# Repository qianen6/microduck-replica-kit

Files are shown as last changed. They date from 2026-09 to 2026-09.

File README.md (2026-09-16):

<!-- changed_branch: main -->
<!-- changed_field: release_snapshot,publication_metadata,readme.community -->
<!-- repository_state: public_ready -->
<!-- release_snapshot: r9_2026_09_16 -->

# Microduck Replica Kit 🦆

**Microduck 社区复刻工程资料 · R9 工程试装版**

整理机械模型、打印文件、硬件路线和数字检查证据，便于复现与交流。当前路线为 **Pi Zero 2 W + OpenRB-150 + 15 个 HD-1910 + OV5647**；最新机械修订来自 2026-09-13，11 件试装打印工程来自 2026-09-14。

> 独立社区项目，与 Pollen Robotics / Hugging Face 无隶属或背书关系。数字检查通过不等于实物、电气或整机制造验证通过；当前仍为工程试装版。

## 从这里开始

| 你想做什么 | 入口 |
|---|---|
| 查看 / 编辑最新整机 | [R9 Blender 模型](models/r9/Microduck_R9_trial.blend) |
| 获取当前 39 件打印几何 | [STL 文件夹](models/r9/stl) · [逐件清单和 SHA-256](models/r9/parts-manifest.json) |
| 在 Bambu Studio 打开试装排版 | [11 件、两盘、已启用支撑的 3MF](printing/r9/R9_11_parts_support.3mf) |
| 理解文件区别、打印单位与使用顺序 | [打印说明](printing/r9/README.md) |
| 查看 R9 修改及未闭合问题 | [工程评估](docs/current/engineering-review.md) · [原始数字检查摘要](models/r9/evidence) |
| 查看当前硬件路线 | [硬件状态表](hardware/CURRENT_HARDWARE.md) |
| 查阅旧版螺丝、材料、接线与选型 | [历史资料索引](docs/history/README.md) |
| 检查本次发布内容与脱敏策略 | [发布说明](docs/PUBLISHING.md) · [验证记录](VERIFICATION.txt) |

## 当前状态

| 项目 | 状态 |
|---|---|
| 当前整机场景 | 113 个对象；39 件打印对象，15 个舵机参考 |
| R9 几何修订 | 11 个原有网格 + 2 个新增打印件；13 个修订网格历史检查闭合、单连通 |
| 相机与电池 | OV5647 孔位/镜头偏置修订、相机承架、可拆电池后盖 |
| 发布文件复核 | 脱敏前后网格、变换、父子层级与材质分配一致；3MF 的 3D 成员一致 |
| 打印工程 | 11 件试装子集，**不是 39 件全机打印包**；保留支撑设置，不发布机器 G-code |
| 实物配合、电气、动力学与行走 | 尚未完成；不得把静态几何检查当作整机验证 |

历史运动抽样覆盖 235 个姿态，仍记录 82 条新增材料相交；其中包含旧模型已存在的阻挡和名义配合。完整运动范围、轴向叠层和负载试验仍待闭合，详见工程评估。

## 快速使用

```bash
git clone https://github.com/qianen6/microduck-replica-kit.git
cd microduck-replica-kit
python tools/verify_publication.py modified
```

Blender 文件可用 Blender 5.2.1 打开；STL 以毫米为单位，采用零件局部坐标，切片前需确认朝向和尺寸。3MF 面向 Bambu P1S / 0.4 mm 喷嘴与纹理 PEI 板，材料与支撑需按自己的机器重新确认、重新切片。

先试装相机承架、电池盖及单关节，再扩展整机。电池标称输出范围、板卡端口额定值不构成 15 舵机动态供电余量证明。

### 重建上游参考装配（历史参考）

```powershell
powershell -ExecutionPolicy Bypass -File scripts/fetch_upstream.ps1
python -m venv .venv
.\.venv\Scripts\python.exe -m pip install -r requirements-geometry.txt
.\.venv\Scripts\python.exe scripts/export_reference_assembly.py upstream/microduck_rl generated/reference-assembly
```

该脚本重建锁定的上游仿真参考，不生成本仓 R9 改件。旧 Rev A 的 XL330 BOM 也不是当前 HD-1910 采购清单。

## 目录

```text
models/r9/          当前 Blender、39 件 STL、逐件清单及历史数字检查
printing/r9/        11 件试装 3MF 与打印说明
hardware/           当前路线说明及旧 Rev A BOM
docs/current/       R9 工程评估
docs/history/       R3–R8 选型、接线、紧固件与材料参考
firmware/reference/ 原厂 OpenRB 桥接参考（非已验证 HD-1910 驱动）
scripts/            上游参考获取和装配导出
tools/              可重复运行的发布检查
proof/              发布差异、哈希及脱敏复核摘要
```

## 交流群：鸭子复现

欢迎交流复刻、打印试装和问题复现。下图由项目维护者提供并指定公开用于入群。

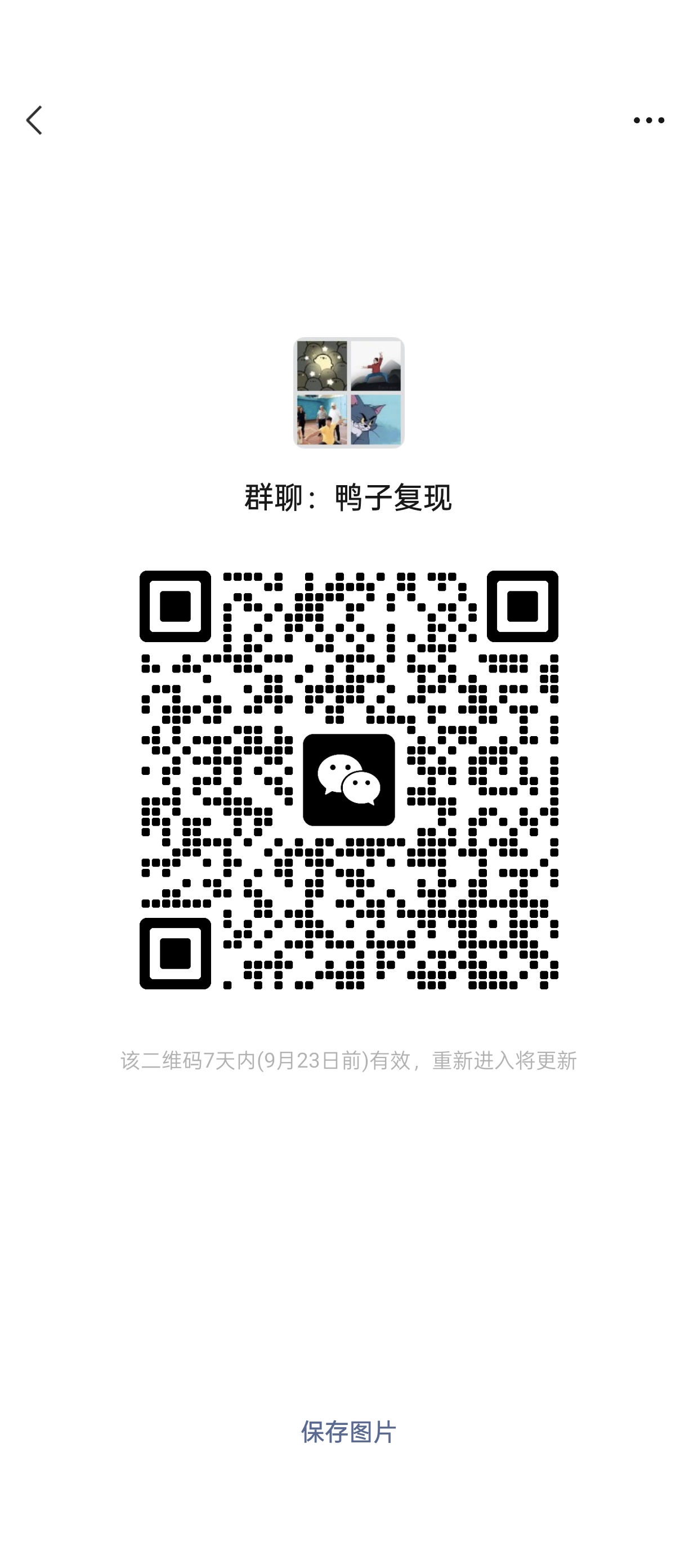
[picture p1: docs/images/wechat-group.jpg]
微信群：鸭子复现


**有效期：图片注明 7 天内、9 月 23 日前有效（本次发布于 2026-09-16）。** 到期后请通过仓库 Issue 请求更新二维码。二维码是本次明确保留的公开联系入口，其余个人/设备信息不随工作区上传。

## 来源与许可证

- [pollen-robotics/microduck](https://github.com/pollen-robotics/microduck)：运行时与控制栈。
- [pollen-robotics/microduck_rl](https://github.com/pollen-robotics/microduck_rl)：仿真几何与训练栈，锁定版本见 [source-lock.json](source-lock.json)。
- [fanhao375/microduck-replica](https://github.com/fanhao375/microduck-replica) 与 [飞特 v2.0 CAD 参考](https://github.com/fanhao375/microduck-replica-cad/releases/tag/v2.0)：复刻研究及 R9 局部接口参考。
- [ROBOTIS OpenRB-150](https://github.com/ROBOTIS-GIT/OpenRB-150)：原厂串口桥接示例。

本仓原创代码和文字使用 Apache-2.0；上游 Microduck 模型衍生的 Blender、STL、3MF 几何按 CC BY-NC-SA 4.0 保留署名与相同方式共享要求。第三方器件外观仅为装配参考，不冒充原厂开放硬件。群二维码仅用于本项目入群，不作模型或代码许可证授权。详见 [NOTICE.md](NOTICE.md)。

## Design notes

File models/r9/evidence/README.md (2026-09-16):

# R9 历史数字检查

本目录保存 2026-09-13 的检查结果及修订计划，经过路径脱敏。不是本次重新运行的动态/电气认证。本次发布仅验证模型几何保持、39 件 STL 导出、3MF 几何与设置保持及隐私检查。

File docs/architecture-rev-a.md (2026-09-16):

# Functional-compatible Rev A

## Target

`functional_compatible_rev_a` preserves the public kinematic layout and the upstream 61-observation / 14-policy-action contract while replacing unavailable manufacturing data with staged measurement and self-designed electronics.

## Architecture

| Subsystem | Rev A target | Evidence state |
|---|---|---|
| Compute | Radxa Zero 3W, RK3566 | high confidence from runtime/device-tree evidence |
| Actuation | 15 compact smart servos; XL330-compatible baseline | high confidence for count and bus layout |
| Policy joints | 14; mouth excluded from policy action | verified in runtime/model |
| Servo bus | UART2, 1 Mbps, 3.3 V TTL half duplex | verified in runtime |
| IMU | LSM6DSV16X, Dynamixel-like ID 200 prototype | data contract verified; PCB absent |
| Depth | VL53L8CX-class 8×8 ToF | optional until locomotion bring-up |
| Camera | IMX219-class CSI camera | optional until locomotion bring-up |
| Battery | removable pack; final rail frozen after bench test | hardware implementation unresolved |
| Audio/NFC | deferred from locomotion Rev A | not required by 50 Hz control loop |

## Stage gates

| Gate | Build | Pass condition |
|---|---|---|
| G0 | source-only | locked commits and deterministic reference export |
| G1 | one actuator | 50 Hz for 30 min; current, voltage, temperature and packet-loss log |
| G2 | print coupon | repeatable M2 insert and bearing fits |
| G3 | one leg | full travel, no harness pinch, 10 min static support |
| G4 | full bus | 15 actuators + IMU; complete read/write within 20 ms |
| G5 | suspended robot | home, sit/stand and fall-to-limp before gait execution |

## Key design rule

Do not bulk-purchase the remaining actuators or freeze battery/PCB design before G1 and G2. The first prototype is a measurement instrument, not a production unit.

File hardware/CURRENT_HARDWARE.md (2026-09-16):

# 当前硬件路线：R9 工程试装

| 模块 | 当前模型对应 | 验证边界 |
|---|---|---|
| 主控 | Raspberry Pi Zero 2 W | 安装参考；系统与真实线束另验 |
| 总线候选 | OpenRB-150（头内） | 原厂桥接为协议参考；HD-1910 主机协议、接插件、电气尚待验证 |
| 舵机 | 15 × HD-1910-C001 | 舵盘配合、轴向叠层、总线及峰值电流待台架 |
| 相机 | OV5647，25 × 24 mm PCB | 孔距 21 × 12.5 mm；板厚 1.2 mm 为模型假设 |
| IMU | BNO08x 板参考 | 实际板型/驱动/时序待确认 |
| 电池 | 6.4 V 磷酸铁锂，19 × 37 × 66 mm 包络 | 商品标示输出 0–3 A；不是已实测连续输出能力 |
| 降压 | MP1584 5 V 模块候选 | 热、压降和带载余量待实测 |
| 开关/声音 | 小拨动开关与 20 mm 扬声器参考 | 电流承载与驱动匹配另验 |

这是硬件路线表，不是完整可下单 BOM。`BOM_REV_A.csv` 是旧 XL330 路线；历史 R6 HAT 接线和 R8 螺丝资料保留版本标签，不能直接用于 R9 全机采购/通电。不得把 3 A 端口或电池广告范围当作 15 舵机电源设计验证。

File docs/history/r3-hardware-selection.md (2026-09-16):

> 历史参考：对应旧版硬件/几何；不得视为 R9 当前 BOM、接线或打印放行。

# Microduck硬件定选与实施方案

> 一套明确的样机硬件主选方案，含采购、接线、改模和验证顺序。

**生成日期:** 2026-09-05

**预计总投入:** 首轮工程时间盒40小时；非交货承诺，物流、返工和完整步态训练另计

---

## 1. 已确认的用户需求简报

- **目标:** 确定一台Microduck复刻样机采用的部件和制作路线，减少反复购买和凭占位图打印。
- **当前起点:** 已有RA2静态模型和采购表；用户指定HD-1910-C001资料包。附件SHA-256：252dad0edfd1560d9bfe5561e065ce00294942c0ce94806dbf183d2f08c6c105，与项目留档相同；图纸页1与照片是舵机参数来源。
- **可用时间:** 按首轮40小时工程时间盒拆解；并非用户已承诺可用工时。
- **语言:** 中文
- **偏好形式:**
  - 决策表
  - 厂家图纸/规格
  - 接线与实施说明
- **期望深度:** 可实施的样机选型；不等同制造放行
- **限制条件:**
  - 保留用户指定舵机路线。
  - 优先可追溯规格与接口，接受为真实硬件修改外壳。
  - 不实际下单，不把未测参数写成已验证。
- **假设:**
  - 目标是一台可开发验证的复刻样机，不追求所有模块立即照搬原厂闭源硬件。
  - PCB交由有电路/布线能力的工程人员与SMT厂实施，先样机后扩量。
  - 预算未指定，优先原厂/授权可追溯件；报价与到货版本另取回执。
- **时间安排边界:**
  - **可用总时长:** 2400 分钟
  - **单次建议时长:** 60 分钟
  - **机动时间比例:** 15%

## 2. 核心指南

### 直接结论

采用本清单的25条主选：HD1910不变，标准2S Gens ace动力电池、Radxa 4GB/32GB与原配Camera 8M219、Pololu升降压/ToF、SparkFun躯干IMU、明确声学件、真实外置急停。两块板按R3架构自制；新硬件入模后再决定整套打印。 [E_battery](#evidence-E_battery) [E_camera](#evidence-E_camera) [E_buck](#evidence-E_buck) [E_imu](#evidence-E_imu) [E_estop](#evidence-E_estop)

### 下一步行动

- **行动:** 先按首批栏拿样件并保存订货回执；把附件中型号混用、协议/控制表和持续负载定义交给舵机厂家补齐。先执行空载/轻载台架验证，再进入承载。
- **时间:** 首个90分钟工作时段
- **预期产出:** 一张带准确型号、配件和资料版本的首批清单
- **证据说明:** [E_debug](#evidence-E_debug) [E_battery](#evidence-E_battery) [E_camera_cable](#evidence-E_camera_cable)

### 真正重要的点

- 官方Radxa相机的32×32板框与旧25×24占位有明确差异，相机托应重画。 [E_camera](#evidence-E_camera)
- 电池与5V供电按高倍率标准LiPo和升降压路线选定；不用未注明放电能力的相机电池作默认动力电源。 [E_battery](#evidence-E_battery) [E_buck](#evidence-E_buck)
- 平衡IMU固定在躯干且需要软件后端修改；头部IMU标记不等于这颗实物传感器。 [E_runtime](#evidence-E_runtime) [E_rl](#evidence-E_rl) [E_imu](#evidence-E_imu)
- 急停只硬切舵机、主控保留供电；所有新方案仍需实机验证。 [E_estop](#evidence-E_estop) [E_power](#evidence-E_power)

### 具体建议

#### 主选：Radxa Camera 8M219 + 原配FPC

- **适合:** 优先接口可追溯与主控配套
- **原因:** 厂家明确支持ZERO3，具有尺寸图与线缆说明。
- **取舍与限制:** 32mm板需要改托架；视角与160°广角模块不同。
- **证据说明:** [E_camera](#evidence-E_camera) [E_camera_cable](#evidence-E_camera_cable)

#### 备选：Waveshare IMX219-160 非IR版，本轮不采购

- **适合:** 把广角视场作为优先目标时
- **原因:** 有明确25×24板框和160°版本。
- **取舍与限制:** 仍需FPC/驱动/光学校验，不作为无改动替换。
- **证据说明:** [E_alt_camera](#evidence-E_alt_camera)

#### 备选：USB TO AUDIO，本轮不采购

- **适合:** 接受另改头部空间、希望减少音频PCB开发时
- **原因:** 现成USB音频模块可缩短模拟电路开发。
- **取舍与限制:** 需USB布线和ALSA适配，本轮选择保留aic3104路线。
- **证据说明:** [E_alt_audio](#evidence-E_alt_audio) [E_codec](#evidence-E_codec)

### 确定采用的硬件与采购顺序

> **本节回答:** 每组只给一个主选型号；首批为0的PCB内含件由板厂配料，避免重复购买。

#### A01 舵机：FEETECH HD-1910-C001（用户指定附件款）

整机15；首批1。附件：本体34×20×23mm，总跨距29mm，孔距30×16mm；资料标称5–8.4V。 安装：原厂舵盘与线束成套，先单关节。 改模：15处安装接口逐一验证；不从混名STEP推定全部固定件相同。 验证：PDF写HD-1910M，STEP文件名HD-1915；缺协议表/连续负载定义。

**具体例子:** 收货记录：FEETECH HD-1910-C001（用户指定附件款）；首批1；型号标签和尺寸照片。

**证据说明:** [E_debug](#evidence-E_debug)

#### C01 主控：Radxa ZERO 3W 4GB RAM + 32GB eMMC，带40针排针；按V1.12/AIC8800询价

整机1；首批1。板框65×30mm；选3W，不替换3E或旧Zero。 安装：保留GPIO配套，安装在头部；与5519A一起入模。 改模：重核版本、元件高度、叠板与散热包络。 验证：实物丝印/内存/eMMC/无线芯片与订单一致。

**具体例子:** 收货记录：Radxa ZERO 3W 4GB RAM + 32GB eMMC，带40针排针；按V1.12/AIC8800询价；首批1；型号标签和尺寸照片。

**证据说明:** [E_radxa](#evidence-E_radxa) [E_radxa_versions](#evidence-E_radxa_versions)

#### C05 散热：Radxa Heatsink 5519A

整机1；首批1。官方ZERO 3W/3E配套型号；完整高度待实物/CAD。 安装：保留天线区域和散热风道。 改模：头壳与HAT叠高重新检查。 验证：封闭头壳下CPU温度与降频测试。

**具体例子:** 收货记录：Radxa Heatsink 5519A；首批1；型号标签和尺寸照片。

**证据说明:** [E_heat](#evidence-E_heat)

#### C06 板间连接：Samtec SSW-120-02-G-D；M2.5母母铜柱12mm

整机1；首批1。40针双排2.54mm；铜柱12mm为初版装配起点。 安装：螺钉与绝缘垫固定，检查排针有效插入深度。 改模：用真实插接组合替换原6mm方块占位。 验证：逐处确认螺钉长度、铜柱接触和电气绝缘。

**具体例子:** 收货记录：Samtec SSW-120-02-G-D；M2.5母母铜柱12mm；首批1；型号标签和尺寸照片。

**证据说明:** [E_header](#evidence-E_header)

#### P02 电池：Gens ace GEA8502S60E2

整机1；首批1。标准LiPo，2S/7.4V/850mAh/60C；约58×32×20mm、55g；EC2+JST-XHR-3P。 安装：保留原厂电池线头；改为圆角托盘与绑带，插头出线侧留缓冲。 改模：原NP-F滑轨/触点锁扣退役；电池座重画。 验证：外形约值与动态电流、保护/低电压需实测。

**具体例子:** 收货记录：Gens ace GEA8502S60E2；首批1；型号标签和尺寸照片。

**证据说明:** [E_battery](#evidence-E_battery)

#### P03 充电：SkyRC B6neo SK-100198

整机1；首批1。标准LiPo 2S平衡充电；首轮0.8A；满电总电压8.4V。 安装：电池取下后接主线及3针平衡口；配成品EC2充电线。 改模：充电器留在机外。 验证：按该型号说明书核对模式与极性，不选LiHV/3S。

**具体例子:** 收货记录：SkyRC B6neo SK-100198；首批1；型号标签和尺寸照片。

**证据说明:** [E_charger](#evidence-E_charger) [E_battery](#evidence-E_battery)

#### P04 主控5V：Pololu S13V30F5 #4082

整机1；首批1。5V升降压，典型约3A，22.9×22.9×9.7mm。 安装：接电池主保险后的独立3A逻辑支路，急停不断这一路。 改模：比D24V50F5更大，支架及间隙重查。 验证：6.4–8.4V输入与0–2.5A负载下测输出、温升和启动。

**具体例子:** 收货记录：Pololu S13V30F5 #4082；首批1；型号标签和尺寸照片。

**证据说明:** [E_buck](#evidence-E_buck)

#### E04 电源与TTL板：自制 PWR-SERVO-R3

整机1；首批0。34×42mm为板框目标；LM74502DDFR+2×CSD18540Q5B；逻辑/舵机分支分开。 安装：共源背靠背NFET；NC急停+上电默认关断/手动ARM；主干分路注入。 改模：按真实贴片保险丝、电容、接线焊盘重新布局。 验证：原理图/PCB/SMT尚未生产；需回馈尖峰、UVLO、保护和热测。

**具体例子:** 收货记录：自制 PWR-SERVO-R3；首批0；型号标签和尺寸照片。

**证据说明:** [E_power](#evidence-E_power) [E_power_reverse](#evidence-E_power_reverse) [E_fet](#evidence-E_fet) [E_fuse](#evidence-E_fuse)

#### E05 音频与接口板：自制 AUDIO-HAT-R3

整机1；首批0。65×30mm、4层1.6mm目标；TLV320AIC3104IRHBR+TPA2010D1YZF；12MHz时钟。 安装：保留项目I2S3/I2C3和aic3104卡名；模拟3.3/1.8V，数字3.3V单独供电。 改模：与散热器、相机、排针同时定叠高；尚非Gerber。 验证：供电时序、录放音、噪声、EMI和布线复核。

**具体例子:** 收货记录：自制 AUDIO-HAT-R3；首批0；型号标签和尺寸照片。

**证据说明:** [E_codec](#evidence-E_codec) [E_amp](#evidence-E_amp) [E_gpio](#evidence-E_gpio) [E_runtime](#evidence-E_runtime)

#### E07 数字3.3V：TPS62162DSGR（HAT内置）

整机1；首批0。1A降压；供ToF、NFC等数字负载，模拟LDO与其分开。 安装：放在HAT数字区，按TI参考电路布置。 改模：新增电感/电容空间，不能只放芯片方块。 验证：SMT供货确认；电流预算与纹波测试。

**具体例子:** 收货记录：TPS62162DSGR（HAT内置）；首批0；型号标签和尺寸照片。

**证据说明:** [E_digital_supply](#evidence-E_digital_supply)

#### S01 平衡IMU：SparkFun Micro LSM6DSV16X SEN-21336

整机1；首批1。7.62×19.05mm板框；3.3V；I2C 0x6B。 安装：刚性固定在躯干，接独立I2C4的27/28；保留坐标标识。 改模：增加躯干小卡座；头部功能标记不充当平衡IMU实体。 验证：新增I2C/SFLP后端并校准坐标；移除对ID200应答的依赖。

**具体例子:** 收货记录：SparkFun Micro LSM6DSV16X SEN-21336；首批1；型号标签和尺寸照片。

**证据说明:** [E_imu](#evidence-E_imu) [E_imu_product](#evidence-E_imu_product) [E_gpio](#evidence-E_gpio) [E_runtime](#evidence-E_runtime) [E_rl](#evidence-E_rl)

#### S02 测距：Pololu VL53L8CX #3419

整机1；首批1。约13×23×3mm；VIN=3.3V，I2C默认7-bit 0x29。 安装：头部前向；SPI/I2C脚接GND，SDA/SCL接I2C3；线长目标≤60mm。 改模：补实体支架与通光开口。 验证：读距、壳体遮挡/反射与总线负载测试。

**具体例子:** 收货记录：Pololu VL53L8CX #3419；首批1；型号标签和尺寸照片。

**证据说明:** [E_tof](#evidence-E_tof)

#### S03 相机：Radxa Camera 8M 219（含ZERO 3配套FPC）

整机1；首批1。板32±0.2mm见方；孔距28±0.1mm；镜头前凸15.98±0.2mm；PCB1.6mm。 安装：使用原配150mm同面22P 0.5→15P 1.0mm排线。 改模：旧25×24相机占位不适用；相机托、镜头座和面罩重画。 验证：前凸不是总厚，需加背部FPC座；视频和内参重标定。

**具体例子:** 收货记录：Radxa Camera 8M 219（含ZERO 3配套FPC）；首批1；型号标签和尺寸照片。

**证据说明:** [E_camera](#evidence-E_camera) [E_camera_cable](#evidence-E_camera_cable)

#### S05 麦克风：Same Sky CMC-4015-25T

整机1；首批1。顶入声模拟驻极体，直径4mm、高1.5mm。 安装：独立胶套/卡座，短线接AIC3104麦克风输入。 改模：按真实厚度、声孔和导声路径重画。 验证：按数据表偏置条件设置MICBIAS与负载，测底噪/灵敏度。

**具体例子:** 收货记录：Same Sky CMC-4015-25T；首批1；型号标签和尺寸照片。

**证据说明:** [E_mic](#evidence-E_mic) [E_codec](#evidence-E_codec)

#### E06 扬声器：PUI Audio AS02008MR-HT-WP

整机1；首批1。20mm直径、3.9mm高、8Ω、额定1.2W。 安装：前后声腔隔离，独立密封圈，接TPA2010差分功率输出。 改模：扬声器托与声孔重画。 验证：校准限幅；8Ω负载2.5Vrms约0.78W作为初始音量测试点。

**具体例子:** 收货记录：PUI Audio AS02008MR-HT-WP；首批1；型号标签和尺寸照片。

**证据说明:** [E_speaker](#evidence-E_speaker) [E_amp](#evidence-E_amp)

#### S06 NFC：Seeed Grove NFC(PN532) 113020006 + 原配天线

整机2；首批1。控制板25.43×20.35mm；天线约28×30.5mm；3.3V。 安装：首轮一套试读，最终两套分走UART4/5；天线分别靠近头盖和喙部非金属区域。 改模：增加板卡与天线固定，避开金属/散热片。 验证：补NFC程序与读距测试；保持原馈线长度，第二套后补。

**具体例子:** 收货记录：Seeed Grove NFC(PN532) 113020006 + 原配天线；首批1；型号标签和尺寸照片。

**证据说明:** [E_nfc](#evidence-E_nfc) [E_nfc_wiring](#evidence-E_nfc_wiring) [E_nfc_antenna](#evidence-E_nfc_antenna) [E_gpio](#evidence-E_gpio)

#### P07 急停：IDEC XA1E-BV302-R

整机1；首批1。16mm安装系列、29mm蘑菇头、2NC。 安装：首版外置有线控制盒；一路NC硬切舵机使能，另一路状态检测；复位后需重新ARM。 改模：旧小按钮占位与12.6mm开孔取消或改控制线出口。 验证：断线/按下/复位/上电顺序均测试，逻辑电源保持。

**具体例子:** 收货记录：IDEC XA1E-BV302-R；首批1；型号标签和尺寸照片。

**证据说明:** [E_estop](#evidence-E_estop) [E_power](#evidence-E_power)

#### FMAIN 主保险丝：Littelfuse 0451015.MRL

整机1；首批0。451系列15A，6.10×2.69×2.69mm。 安装：靠电池入口布置，额定值作为首版样机起点。 改模：删除旧汽车片式保险丝座占位。 验证：最终按电流波形、I²t、导线与PCB温升复核。

**具体例子:** 收货记录：Littelfuse 0451015.MRL；首批0；型号标签和尺寸照片。

**证据说明:** [E_fuse](#evidence-E_fuse)

#### FBRANCH 舵机支路保险丝：Littelfuse 0451005.MRL

整机3；首批0。451系列5A，每组5舵机一路，首版样机值。 安装：三路分支分别保护，主干后分点供电，不让首颗细线承担整组电流。 改模：按贴片封装重布电源板。 验证：不是精确电机限流器；过载保护与正常瞬态区分。

**具体例子:** 收货记录：Littelfuse 0451005.MRL；首批0；型号标签和尺寸照片。

**证据说明:** [E_fuse](#evidence-E_fuse)

#### FLOGIC 逻辑支路保险丝：Littelfuse 0451003.MRL

整机1；首批0。451系列3A，位于5V变换器输入侧。 安装：急停之前分出逻辑支路，断总电源仍用电池插头。 改模：更新配电走线及熔断器分组。 验证：检查冷启动和满负载浪涌。

**具体例子:** 收货记录：Littelfuse 0451003.MRL；首批0；型号标签和尺寸照片。

**证据说明:** [E_fuse](#evidence-E_fuse) [E_buck](#evidence-E_buck)

#### CAP 支路储能：Panasonic EEUFR1C471

整机3；首批0。16V、470µF、直径8mm、长11.5mm。 安装：横置并固定，引脚/外壳绝缘，靠近分支。 改模：旧10mm长度占位增加1.5mm。 验证：纹波、额定寿命及回馈电压测试。

**具体例子:** 收货记录：Panasonic EEUFR1C471；首批0；型号标签和尺寸照片。

**证据说明:** [E_cap](#evidence-E_cap)

#### E02 台架调试：FEETECH FE-URT1-C001

整机1；首批1。52×38.4×16mm，USB转TTL/485，最高1Mbps。 安装：只放台架，选TTL通道；电源按HD1910限制设定。 改模：不塞入鸭子机身。 验证：工具支持TTL不等于HD1910协议兼容已证明。

**具体例子:** 收货记录：FEETECH FE-URT1-C001；首批1；型号标签和尺寸照片。

**证据说明:** [E_debug](#evidence-E_debug)

#### W01 舵机端线束：HD-1910原厂配套线束，按实际插座批次

整机15；首批2。端子规格、针序由厂家对这批HD1910确认。 安装：保留原厂端子；D/V/G按标记与连通性核对，不凭线色推定。 改模：完整插头、应力缓冲和全行程线束加入模型。 验证：原包未明确的端子尺寸仍需厂家回执。

**具体例子:** 收货记录：HD-1910原厂配套线束，按实际插座批次；首批2；型号标签和尺寸照片。

**证据说明:** [E_debug](#evidence-E_debug)

#### W02 电源主干：W-PWR-R3：EC2设备端输入；18AWG高股数硅胶红黑线

整机1；首批1。电池保留原厂EC2；机器人侧加工成品配套线束。 安装：输入和回流同线规；三支路接AMASS XT30U成对插头；信号另走。 改模：建完整对接外形而非单端小方块。 验证：极性、端子版本、接触压降与拉脱力检查。

**具体例子:** 收货记录：W-PWR-R3：EC2设备端输入；18AWG高股数硅胶红黑线；首批1；型号标签和尺寸照片。

**证据说明:** [E_battery](#evidence-E_battery) [E_fuse](#evidence-E_fuse)

#### W03 传感器与急停线束：Qwiic JST-SH-4；Grove原配线；急停JST-GH-4成对线束

整机1；首批1。传感器逻辑统一3.3V；SH 1.0mm与GH 1.25mm分开。 安装：传感器各按丝印接，急停只走低电流控制；转轴附近留随动弯线。 改模：逐根定义净空和弯折区域；首版线长留余量后实装裁定。 验证：端子、屏蔽/回流、极限角不夹线检查。

**具体例子:** 收货记录：Qwiic JST-SH-4；Grove原配线；急停JST-GH-4成对线束；首批1；型号标签和尺寸照片。

**证据说明:** [E_gpio](#evidence-E_gpio) [E_tof](#evidence-E_tof) [E_imu](#evidence-E_imu) [E_nfc_wiring](#evidence-E_nfc_wiring)

### 两块自制板怎么做

> **本节回答:** 给出实现边界，不把机械板框当成现成电子板。

#### 配电分成常供逻辑和可断舵机两路

电池→主保险丝→节点A。A→3A逻辑保险丝→S13V30F5→5V_LOGIC；A→LM74502+共源背靠背NFET→三路5A保险丝→15舵机。所有额定值是首版测试值，不是已实测工作电流。

**具体例子:** 核对位置：p1 / Pin functions / Typical application

**证据说明:** [E_power](#evidence-E_power) [E_buck](#evidence-E_buck) [E_fuse](#evidence-E_fuse)

#### 急停与手动复位

IDEC的NC回路打开或线缆断开即硬件关断舵机使能；另一个NC作状态检测。上电默认关断，松开急停后仍等待ARM。主控逻辑电源保持，便于记录故障和正常关机。逻辑闭锁电路属于PWR板设计任务，尚未在实机验证。

**具体例子:** 核对位置：Key Features / Mechanical Specifications

**证据说明:** [E_estop](#evidence-E_estop) [E_power](#evidence-E_power)

#### 逻辑常供仍有欠压截止

常供只表示急停时保留主控，不表示无限放电。项目初始目标为6.6V预警/系统关机、6.4V舵机关闭、6.2V逻辑硬截止并锁定；升降压2.8V最低输入不是2S电池截止值。逐节欠压与失衡检查纳入PWR设计，阈值需结合公差、压降和实测修订。

**具体例子:** 核对位置：Product Specs：Capacity、Voltage、C rate、Dimensions、Balance Plug、Discharge Plug

**证据说明:** [E_battery](#evidence-E_battery) [E_buck](#evidence-E_buck) [E_power](#evidence-E_power)

#### 回馈与欠压不照搬旧值

选择LM74502而非原LM74800，导通时保留回馈到电池的路径。关断后仍需处理母线回馈尖峰。UVLO目标约6.4V，但电阻值需按新芯片阈值/公差重算；SMBJ12A不是8.4V舵机保护的充分方案。

**具体例子:** 核对位置：p1 / Pin functions / Typical application

**证据说明:** [E_power](#evidence-E_power) [E_power_reverse](#evidence-E_power_reverse) [E_battery](#evidence-E_battery)

#### 音频主路线保持AIC3104

AUDIO-HAT-R3沿用AIC3104+TPA2010D1和12MHz时钟，目标65×30mm、4层1.6mm。模拟3.3V/内核1.8V与数字3.3V分区。QFN/小封装由SMT厂贴装，先确认电路再固定板框。

**具体例子:** 核对位置：Pin functions / Power / Digital interface

**证据说明:** [E_codec](#evidence-E_codec) [E_amp](#evidence-E_amp) [E_header](#evidence-E_header)

#### 新增数字3.3V供电

TPS62162 1A数字电源供测距/NFC等负载；旧300mA模拟LDO不承担所有模块。设计预算为ToF 150mA+双NFC 166mA+IMU及其他余量，而非实测功耗。供货由SMT厂确认。

**具体例子:** 核对位置：Features / Part details

**证据说明:** [E_digital_supply](#evidence-E_digital_supply) [E_tof](#evidence-E_tof) [E_nfc_wiring](#evidence-E_nfc_wiring)

#### 线束按功能加工

舵机端保留原厂端子与线序证据。主供电/回流同线规，信号与大电流分开；每腿分点供电。CSI在头内使用原配线；颈部线束留随动弯曲，不穿实心轴，逐关节扫角后确定最终线长。

**具体例子:** 核对位置：Default FPC / FPC Cable

**证据说明:** [E_camera_cable](#evidence-E_camera_cable) [E_gpio](#evidence-E_gpio) [E_debug](#evidence-E_debug)

### 接线与软件要同步改的部分

> **本节回答:** 以下为接口分配方案；设备树、Linux设备节点和实际电气状态仍须在样机上核对。

#### GPIO2/4 · 5V_LOGIC

S13V30F5输出。两根5V及足够地针共同供电；与USB供电不并联

**具体例子:** 核对位置：40 PIN GPIO / Debug Serial / MIPI CSI

**证据说明:** [E_gpio](#evidence-E_gpio) [E_runtime](#evidence-E_runtime)

#### GPIO8 / 10 · UART2 TX / RX

PWR板TTL电路→HD1910。关闭串口控制台/引导输入干扰后使用

**具体例子:** 核对位置：40 PIN GPIO / Debug Serial / MIPI CSI

**证据说明:** [E_gpio](#evidence-E_gpio) [E_runtime](#evidence-E_runtime)

#### GPIO3 / 5 · I2C3 SDA / SCL

AIC3104 0x18 + ToF 0x29。沿用项目对应overlay；检查总线上拉组合

**具体例子:** 核对位置：40 PIN GPIO / Debug Serial / MIPI CSI

**证据说明:** [E_gpio](#evidence-E_gpio) [E_runtime](#evidence-E_runtime)

#### GPIO12 / 35 / 40 / 38 · I2S3 BCLK / LRCLK / TX / RX

AUDIO-HAT-R3。12MHz独立codec时钟；保留aic3104卡名

**具体例子:** 核对位置：40 PIN GPIO / Debug Serial / MIPI CSI

**证据说明:** [E_gpio](#evidence-E_gpio) [E_runtime](#evidence-E_runtime)

#### GPIO27 / 28 · I2C4 SDA / SCL

躯干LSM6DSV16X 0x6B。保持默认GPIO/I2C布线，不改成USB信号

**具体例子:** 核对位置：40 PIN GPIO / Debug Serial / MIPI CSI

**证据说明:** [E_gpio](#evidence-E_gpio) [E_runtime](#evidence-E_runtime)

#### GPIO16 / 18 · UART4 RX / TX

头部Grove NFC TX / RX。3.3V UART，模块保留默认UART模式

**具体例子:** 核对位置：40 PIN GPIO / Debug Serial / MIPI CSI

**证据说明:** [E_gpio](#evidence-E_gpio) [E_runtime](#evidence-E_runtime)

#### GPIO33 / 32 · UART5 RX / TX

喙部Grove NFC TX / RX。独立串口避免同地址I2C模块冲突

**具体例子:** 核对位置：40 PIN GPIO / Debug Serial / MIPI CSI

**证据说明:** [E_gpio](#evidence-E_gpio) [E_runtime](#evidence-E_runtime)

#### GPIO7 / 11 / 15 · ESTOP_STATUS / SOFTWARE_KILL / BAT_LOW

PWR板控制接口。软件只可附加关断，NC硬断链优先；低电量先通知主控关机

**具体例子:** 核对位置：40 PIN GPIO / Debug Serial / MIPI CSI

**证据说明:** [E_gpio](#evidence-E_gpio) [E_runtime](#evidence-E_runtime)

#### GPIO6/9/14/20/25/30/34/39 · GND

公共信号参考/电源回流。电机大电流不通过传感器细地线返回

**具体例子:** 核对位置：40 PIN GPIO / Debug Serial / MIPI CSI

**证据说明:** [E_gpio](#evidence-E_gpio) [E_runtime](#evidence-E_runtime)

#### IMU不再伪装成ID200设备

使用同型号LSM6DSV16X，但通过独立I2C4读取SFLP。新增I2C后端并从电机同步读ID列表移除200，将带时间戳的陀螺仪/四元数交给Sensors。保持单位、躯干坐标、过期检测和就绪条件；零样本不当作正常姿态。

**具体例子:** 核对位置：Board Outline / I2C / Power

**证据说明:** [E_imu](#evidence-E_imu) [E_runtime](#evidence-E_runtime) [E_rl](#evidence-E_rl)

#### 相机尺寸已实证纠正

Radxa官方图纸是32×32mm，旧模型25×24mm占位需要改。孔距28mm；镜头前凸15.98mm之外还有PCB和背部连接器。使用原配同面转接FPC，优先官方支持链路，接受广角范围不同并重新标定。

**具体例子:** 核对位置：印刷页5 Physical specifications；页4 FPC

**证据说明:** [E_camera](#evidence-E_camera) [E_camera_cable](#evidence-E_camera_cable) [E_alt_camera](#evidence-E_alt_camera)

#### 舵机由用户资料锁定，协议仍是原厂交付项

附件已重开并与项目留档SHA-256逐字节比对相同。它包含PDF/STEP/图片而没有协议与控制表；PDF和STEP型号文字不同。这里采用HD-1910-C001，不用FE-URT1兼容列表代替该舵机协议证明。

**具体例子:** 核对位置：FE-URT-1条目

**证据说明:** [E_debug](#evidence-E_debug) [E_runtime](#evidence-E_runtime)

### 下一版模型明确改哪些地方

> **本节回答:** R3选型没有自动成为RA3装配或打印放行。RA2模型本轮保持原样。

#### 电池座与躯干

用58×32×20mm动力电池代替NP-F滑轨电池；重画圆角托盘、绑带槽、线头缓冲和插拔区域。软包不能由螺钉顶压，按到货尺寸留制造余量。

**具体例子:** 核对位置：Product Specs：Capacity、Voltage、C rate、Dimensions、Balance Plug、Discharge Plug

**证据说明:** [E_battery](#evidence-E_battery)

#### 头部与散热叠层

将32mm相机、5519A、真实排针及铜柱同时入模，重画相机托和面罩；如果叠高不足，改壳而不是省略散热体。

**具体例子:** 核对位置：印刷页5 Physical specifications；页4 FPC

**证据说明:** [E_camera](#evidence-E_camera) [E_heat](#evidence-E_heat) [E_header](#evidence-E_header)

#### 传感器与声学支架

新增躯干IMU卡座、ToF通光孔、声学密封与声孔、两套NFC板/天线固定。NFC不要紧贴散热片；保留原配馈线。

**具体例子:** 核对位置：Board Outline / I2C / Power

**证据说明:** [E_imu](#evidence-E_imu) [E_tof](#evidence-E_tof) [E_speaker](#evidence-E_speaker) [E_mic](#evidence-E_mic) [E_nfc_wiring](#evidence-E_nfc_wiring)

#### 电源板和急停出口

用6.1mm贴片保险丝代替虚构小汽车保险丝座；三颗电容按11.5mm长度；升降压按22.9mm方板；原12.6mm急停开口改成控制线出口或恢复壳体。

**具体例子:** 核对位置：p1–3 电气特性/时间电流曲线/外形

**证据说明:** [E_fuse](#evidence-E_fuse) [E_cap](#evidence-E_cap) [E_buck](#evidence-E_buck) [E_estop](#evidence-E_estop)

#### 资料通过与实装通过分开

本次已核对来源和接口逻辑；还未做新选型的切片、全角度碰撞、载荷/温升与实物装配。材料、PCB与新模型通过对应测试后再整套打印。

**具体例子:** 核对位置：本地同源 duck-control/src/imu.rs、bus.rs、deploy/audio/*.dts

**证据说明:** [E_runtime](#evidence-E_runtime) [E_rl](#evidence-E_rl)

## 3. 精选资源

### 资源配置策略

比较了电池、音频与相机路线；以厂家参数和本地软件约束收敛主选，备选单列。

- **已审查候选资料:** 40
- **已选入资料:** 32
- **媒介:** text
- **内容用途:** reference

> 只收厂家规格、应用说明和源代码；不强制加入课程或视频。

### 选择适合你的路线

<!-- atlas-track:1 -->
#### 先采购与试配

- **适合:** 先完成首批样件与尺寸复核
- **节奏:** 每次30–60分钟，按阶段输入推进

**指定资源**

- [Gens ace 850mAh 7.4V 2S1P 60C EC2](https://gensace.de/products/gens-ace-850mah-7-4v-2s1p-60c-lipo-battery-pack-with-ec2-plug) — **使用位置:** Product Specs：Capacity、Voltage、C rate、Dimensions、Balance Plug、Discharge Plug; **推荐理由:** GEA8502S60E2；7.4V/850mAh/60C；约58×32×20mm、55g；EC2和JST-XHR-3P。 · **必做**
- [Radxa Camera 8M 219 Product Brief Rev 1.0](https://dl.radxa.com/accessories/camera-8m-219/radxa_camera_8m_219_product_brief_Revision_1.0.pdf) — **使用位置:** 印刷页5 Physical specifications；页4 FPC; **推荐理由:** 板32±0.2mm见方，孔距28±0.1mm，孔径2±0.1mm；镜头前凸15.98±0.2mm，PCB1.6mm；背面连接器另计。 · **必做**
- [Radxa Heatsink 5519A](https://radxa.com/products/accessories/heatsink-5519a/) — **使用位置:** 适配机型; **推荐理由:** 5519A为ZERO 3W/3E配套散热器。 · **必做**
- [LSM6DSV16X Hardware Overview](https://docs.sparkfun.com/SparkFun_6DoF_LSM6DSV16X/hardware_overview/) — **使用位置:** Board Outline / I2C / Power; **推荐理由:** Micro版SEN-21336为0.3×0.75英寸，即7.62×19.05mm；I2C默认0x6B；3.3V使用。 · **必做**
- [VL53L8CX Carrier #3419](https://www.pololu.com/product/3419) — **使用位置:** Features / Connections; **推荐理由:** 约13×23×3mm；3.2–5.5V；峰值150mA；I/O跟随VIN；SPI/I2C脚拉低选择I2C。 · **必做**
- [XA1E-BV302-R](https://www.idec.com/en-us/switches-indicator-lights/switches-pushbuttons/emergency-stop-switches/xa-16mm-estop/xa1e-bv302-r) — **使用位置:** Key Features / Mechanical Specifications; **推荐理由:** 16mm安装系列、29mm红蘑菇头、2NC、焊接端子。 · **必做**

<!-- /atlas-track -->

<!-- atlas-track:2 -->
#### 电路与软件实施

- **适合:** PCB/固件与整机集成人员
- **节奏:** 按原理图、布线、测试分段查阅

**指定资源**

- [LM74502DDFR](https://www.ti.com/lit/ds/symlink/lm74502.pdf) — **使用位置:** p1 / Pin functions / Typical application; **推荐理由:** 3.2–65V控制器，外接共源背靠背NFET；EN/UVLO拉低关断；导通时不提供反向电流阻断。 · **必做**
- [LM74502 bidirectional current application](https://e2e.ti.com/support/power-management-group/power-management/f/power-management-forum/1503649/lm74502-lm74502-as-high-side-driver-in-back-to-back-connected-com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) — **使用位置:** TI工程师答复; **推荐理由:** 共源背靠背NFET在控制器有效且栅极导通时允许双向电流。 · **必做**
- [451/453 Series Nano2 Fuse](https://www.littelfuse.com/assetdocs/fuse-451-and-453-datasheet?assetguid=533cd5cc-956c-4243-867f-6ab5a62f6ba1) — **使用位置:** p1–3 电气特性/时间电流曲线/外形; **推荐理由:** 451系列贴片保险丝，约6.10×2.69×2.69mm；规格覆盖3A、5A和15A。 · **必做**
- [TLV320AIC3104](https://www.ti.com/lit/ds/symlink/tlv320aic3104.pdf) — **使用位置:** Pin functions / Power / Digital interface; **推荐理由:** 保留AIC3104的I2S/I2C音频路线；IO/模拟3.3V、内核1.8V；具体供电与时序按数据表。 · **必做**
- [ZERO 3 Hardware Interface](https://docs.radxa.com/en/zero/zero3/hardware-design/hardware-interface) — **使用位置:** 40 PIN GPIO / Debug Serial / MIPI CSI; **推荐理由:** GPIO为3.3V；UART2占8/10；I2C4占27/28；UART4占16/18；UART5占32/33。 · **必做**
- [Microduck software repository](https://github.com/pollen-robotics/microduck) — **使用位置:** 本地同源 duck-control/src/imu.rs、bus.rs、deploy/audio/*.dts; **推荐理由:** 本地运行时要求躯干IMU；旧实现从Dynamixel ID200读取12字节；音频使用aic3104卡名。 · **必做**
- [Microduck RL repository](https://github.com/pollen-robotics/microduck_rl) — **使用位置:** 本地 robot_allcollisions.xml 的 sensor/site 与 microduck_constants.py; **推荐理由:** 本地训练传感器引用trunk_base的imu站点，而非head_imu；执行器仍是xl330/m6。 · **必做**

<!-- /atlas-track -->

### 按用途浏览

<!-- atlas-collection:1 -->
#### 硬件主选与规格

采购和建模查阅

- [Gens ace 850mAh 7.4V 2S1P 60C EC2](https://gensace.de/products/gens-ace-850mah-7-4v-2s1p-60c-lipo-battery-pack-with-ec2-plug)
- [Radxa ZERO 3W](https://radxa.com/products/zeros/zero3w/)
- [ZERO 3 Hardware Design Downloads](https://docs.radxa.com/en/zero/zero3/download)
- [ZERO 3 Hardware Interface](https://docs.radxa.com/en/zero/zero3/hardware-design/hardware-interface)
- [Radxa Heatsink 5519A](https://radxa.com/products/accessories/heatsink-5519a/)
- [Radxa Camera 8M 219 Product Brief Rev 1.0](https://dl.radxa.com/accessories/camera-8m-219/radxa_camera_8m_219_product_brief_Revision_1.0.pdf)
- [Radxa Camera 8M 219](https://docs.radxa.com/en/accessories/camera/camera-8m-219)
- [LSM6DSV16X Hardware Overview](https://docs.sparkfun.com/SparkFun_6DoF_LSM6DSV16X/hardware_overview/)
- [SparkFun LSM6DSV16X Hookup Guide](https://docs.sparkfun.com/SparkFun_6DoF_LSM6DSV16X/)
- [VL53L8CX Carrier #3419](https://www.pololu.com/product/3419)
- [AS02008MR-HT-WP](https://puiaudio.com/product/speakers-and-receivers/as02008mr-ht-wp)
- [CMC-4015-25T](https://www.sameskydevices.com/product/audio/microphones/electret-condenser-microphones/cmc-4015-25t)
- [TLV320AIC3104](https://www.ti.com/lit/ds/symlink/tlv320aic3104.pdf)
- [TPA2010D1](https://www.ti.com/lit/ds/symlink/tpa2010d1.pdf)
- [S13V30F5 #4082](https://www.pololu.com/product/4082)
- [LM74502DDFR](https://www.ti.com/lit/ds/symlink/lm74502.pdf)
- [CSD18540Q5B](https://www.ti.com/lit/gpn/CSD18540Q5B)
- [TPS62162DSGR](https://www.ti.com/product/TPS62162/part-details/TPS62162DSGR)
- [451/453 Series Nano2 Fuse](https://www.littelfuse.com/assetdocs/fuse-451-and-453-datasheet?assetguid=533cd5cc-956c-4243-867f-6ab5a62f6ba1)
- [EEUFR1C471](https://industrial.panasonic.com/kr/products/pt/aluminum-cap-lead/models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)
- [XA1E-BV302-R](https://www.idec.com/en-us/switches-indicator-lights/switches-pushbuttons/emergency-stop-switches/xa-16mm-estop/xa1e-bv302-r)
- [Grove NFC PN532 113020006](https://www.seeedstudio.com/Grove-NFC.html)
- [Grove NFC Wiki](https://wiki.seeedstudio.com/Grove_NFC/)
- [B6neo Series](https://www.skyrc.com/b6neo-series)
- [FE-URT-1 Programmer](https://www.feetechrc.com/serial-port-series-steering-gear_50681.html)
- [SSW-120-02-G-D](https://www.samtec.com/products/ssw-120-02-g-d)

<!-- /atlas-collection -->

<!-- atlas-collection:2 -->
#### 应用支持与接口

解决双向电流、天线及驱动问题

- [LM74502 bidirectional current application](https://e2e.ti.com/support/power-management-group/power-management/f/power-management-forum/1503649/lm74502-lm74502-as-high-side-driver-in-back-to-back-connected-com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)
- [NFC Antenna Dimensions](https://forum.seeedstudio.com/t/nfc-antenna-dimensions/6776)
- [Microduck software repository](https://github.com/pollen-robotics/microduck)
- [Microduck RL repository](https://github.com/pollen-robotics/microduck_rl)

<!-- /atlas-collection -->

<!-- atlas-collection:3 -->
#### 本轮未采用的备选

仅在对应取舍改变时使用

- [IMX219-160 Camera](https://www.waveshare.com/product/risc-v/cameras/imx219-160-camera.htm)
- [USB TO AUDIO](https://www.waveshare.com/product/usb-to-audio.htm)

<!-- /atlas-collection -->

### 资源详情

#### [Gens ace 850mAh 7.4V 2S1P 60C EC2](https://gensace.de/products/gens-ace-850mah-7-4v-2s1p-60c-lipo-battery-pack-with-ec2-plug)

- **作者或机构:** Gens ace
- **来源渠道:** 厂家规格与手册
- **类型:** 技术参考
- **用途:** 核对所选型号与接口
- **级别:** 工程实施
- **形式:** 网页、图纸或源代码
- **所需时间:** 按所列章节查阅，约5–15分钟
- **适合:** 该部件采购、布板和安装复核
- **获取方式:** 公开资料；采购价格、库存与地区供货需实际询价
- **优先级:** core
- **媒介:** text
- **内容用途:** reference
- **语言:** 英文为主
- **版本或更新情况:** 核对日期2026-09-05；版本信息见具体资料
- **验证日期:** 2026-09-05

**推荐理由:** GEA8502S60E2；7.4V/850mAh/60C；约58×32×20mm、55g；EC2和JST-XHR-3P。

**重点:** Product Specs：Capacity、Voltage、C rate、Dimensions、Balance Plug、Discharge Plug

**局限:** 网页库存标记混杂，尺寸为约值；C数是厂家标称而非本机实测。

**核验说明:** 核对了型号、对应规格或本地同源代码；网页库存标记混杂，尺寸为约值；C数是厂家标称而非本机实测。

#### [Radxa ZERO 3W](https://radxa.com/products/zeros/zero3w/)

- **作者或机构:** Radxa
- **来源渠道:** 厂家规格与手册
- **类型:** 技术参考
- **用途:** 核对所选型号与接口
- **级别:** 工程实施
- **形式:** 网页、图纸或源代码
- **所需时间:** 按所列章节查阅，约5–15分钟
- **适合:** 该部件采购、布板和安装复核
- **获取方式:** 公开资料；采购价格、库存与地区供货需实际询价
- **优先级:** core
- **媒介:** text
- **内容用途:** reference
- **语言:** 英文为主
- **版本或更新情况:** 核对日期2026-09-05；版本信息见具体资料
- **验证日期:** 2026-09-05

**推荐理由:** RK3566；可选eMMC与40针排针；22针0.5mm CSI；官方列出配套散热器和相机。

**重点:** 接口与配件

**局限:** 具体内存/eMMC和PCB版本以订货回执与丝印为准。

**核验说明:** 核对了型号、对应规格或本地同源代码；具体内存/eMMC和PCB版本以订货回执与丝印为准。

#### [ZERO 3 Hardware Design Downloads](https://docs.radxa.com/en/zero/zero3/download)

- **作者或机构:** Radxa
- **来源渠道:** 厂家规格与手册
- **类型:** 技术参考
- **用途:** 核对所选型号与接口
- **级别:** 工程实施
- **形式:** 网页、图纸或源代码
- **所需时间:** 按所列章节查阅，约5–15分钟
- **适合:** 该部件采购、布板和安装复核
- **获取方式:** 公开资料；采购价格、库存与地区供货需实际询价
- **优先级:** recommended
- **媒介:** text
- **内容用途:** reference
- **语言:** 英文为主
- **版本或更新情况:** 核对日期2026-09-05；版本信息见具体资料
- **验证日期:** 2026-09-05

**推荐理由:** V1.11与V1.12(AIC8800)分别提供图纸；旧3D文件不自动证明新板元件高度一致。

**重点:** Hardware Design

**局限:** 本地旧STEP有效性问题未在本轮消除。

**核验说明:** 核对了型号、对应规格或本地同源代码；本地旧STEP有效性问题未在本轮消除。

#### [ZERO 3 Hardware Interface](https://docs.radxa.com/en/zero/zero3/hardware-design/hardware-interface)

- **作者或机构:** Radxa
- **来源渠道:** 厂家规格与手册
- **类型:** 技术参考
- **用途:** 核对所选型号与接口
- **级别:** 工程实施
- **形式:** 网页、图纸或源代码
- **所需时间:** 按所列章节查阅，约5–15分钟
- **适合:** 该部件采购、布板和安装复核
- **获取方式:** 公开资料；采购价格、库存与地区供货需实际询价
- **优先级:** recommended
- **媒介:** text
- **内容用途:** reference
- **语言:** 英文为主
- **版本或更新情况:** 核对日期2026-09-05；版本信息见具体资料
- **验证日期:** 2026-09-05

**推荐理由:** GPIO为3.3V；UART2占8/10；I2C4占27/28；UART4占16/18；UART5占32/33。

**重点:** 40 PIN GPIO / Debug Serial / MIPI CSI

**局限:** UART2默认兼任控制台；需处理启动日志与引导输入。

**核验说明:** 核对了型号、对应规格或本地同源代码；UART2默认兼任控制台；需处理启动日志与引导输入。

#### [Radxa Heatsink 5519A](https://radxa.com/products/accessories/heatsink-5519a/)

- **作者或机构:** Radxa
- **来源渠道:** 厂家规格与手册
- **类型:** 技术参考
- **用途:** 核对所选型号与接口
- **级别:** 工程实施
- **形式:** 网页、图纸或源代码
- **所需时间:** 按所列章节查阅，约5–15分钟
- **适合:** 该部件采购、布板和安装复核
- **获取方式:** 公开资料；采购价格、库存与地区供货需实际询价
- **优先级:** recommended
- **媒介:** text
- **内容用途:** reference
- **语言:** 英文为主
- **版本或更新情况:** 核对日期2026-09-05；版本信息见具体资料
- **验证日期:** 2026-09-05

**推荐理由:** 5519A为ZERO 3W/3E配套散热器。

**重点:** 适配机型

**局限:** 官网正文未列完整高度，本轮不虚构其包络；到货或有效CAD后复核叠高。

**核验说明:** 核对了型号、对应规格或本地同源代码；官网正文未列完整高度，本轮不虚构其包络；到货或有效CAD后复核叠高。

#### [Radxa Camera 8M 219 Product Brief Rev 1.0](https://dl.radxa.com/accessories/camera-8m-219/radxa_camera_8m_219_product_brief_Revision_1.0.pdf)

- **作者或机构:** Radxa
- **来源渠道:** 厂家规格与手册
- **类型:** 技术参考
- **用途:** 核对所选型号与接口
- **级别:** 工程实施
- **形式:** 网页、图纸或源代码
- **所需时间:** 按所列章节查阅，约5–15分钟
- **适合:** 该部件采购、布板和安装复核
- **获取方式:** 公开资料；采购价格、库存与地区供货需实际询价
- **优先级:** core
- **媒介:** text
- **内容用途:** reference
- **语言:** 英文为主
- **版本或更新情况:** 核对日期2026-09-05；版本信息见具体资料
- **验证日期:** 2026-09-05

**推荐理由:** 板32±0.2mm见方，孔距28±0.1mm，孔径2±0.1mm；镜头前凸15.98±0.2mm，PCB1.6mm；背面连接器另计。

**重点:** 印刷页5 Physical specifications；页4 FPC

**局限:** 前凸尺寸不是整个模组总厚；旧25×24占位和M12镜头座需要改。

**核验说明:** 核对了型号、对应规格或本地同源代码；前凸尺寸不是整个模组总厚；旧25×24占位和M12镜头座需要改。

#### [Radxa Camera 8M 219](https://docs.radxa.com/en/accessories/camera/camera-8m-219)

- **作者或机构:** Radxa
- **来源渠道:** 厂家规格与手册
- **类型:** 技术参考
- **用途:** 核对所选型号与接口
- **级别:** 工程实施
- **形式:** 网页、图纸或源代码
- **所需时间:** 按所列章节查阅，约5–15分钟
- **适合:** 该部件采购、布板和安装复核
- **获取方式:** 公开资料；采购价格、库存与地区供货需实际询价
- **优先级:** core
- **媒介:** text
- **内容用途:** reference
- **语言:** 英文为主
- **版本或更新情况:** 核对日期2026-09-05；版本信息见具体资料
- **验证日期:** 2026-09-05

**推荐理由:** 原配150mm同面22P 0.5mm转15P 1.0mm，官方明确支持ZERO 3W/3E。

**重点:** Default FPC / FPC Cable

**局限:** 资料同时出现不同视角口径，按D74/H62/V49作初始标定参考，最终重标定。

**核验说明:** 核对了型号、对应规格或本地同源代码；资料同时出现不同视角口径，按D74/H62/V49作初始标定参考，最终重标定。

#### [LSM6DSV16X Hardware Overview](https://docs.sparkfun.com/SparkFun_6DoF_LSM6DSV16X/hardware_overview/)

- **作者或机构:** SparkFun
- **来源渠道:** 厂家规格与手册
- **类型:** 技术参考
- **用途:** 核对所选型号与接口
- **级别:** 工程实施
- **形式:** 网页、图纸或源代码
- **所需时间:** 按所列章节查阅，约5–15分钟
- **适合:** 该部件采购、布板和安装复核
- **获取方式:** 公开资料；采购价格、库存与地区供货需实际询价
- **优先级:** core
- **媒介:** text
- **内容用途:** reference
- **语言:** 英文为主
- **版本或更新情况:** 核对日期2026-09-05；版本信息见具体资料
- **验证日期:** 2026-09-05

**推荐理由:** Micro版SEN-21336为0.3×0.75英寸，即7.62×19.05mm；I2C默认0x6B；3.3V使用。

**重点:** Board Outline / I2C / Power

**局限:** 模组不是Dynamixel ID200设备；需要新的I2C读取后端。

**核验说明:** 核对了型号、对应规格或本地同源代码；模组不是Dynamixel ID200设备；需要新的I2C读取后端。

#### [SparkFun LSM6DSV16X Hookup Guide](https://docs.sparkfun.com/SparkFun_6DoF_LSM6DSV16X/)

- **作者或机构:** SparkFun
- **来源渠道:** 厂家规格与手册
- **类型:** 技术参考
- **用途:** 核对所选型号与接口
- **级别:** 工程实施
- **形式:** 网页、图纸或源代码
- **所需时间:** 按所列章节查阅，约5–15分钟
- **适合:** 该部件采购、布板和安装复核
- **获取方式:** 公开资料；采购价格、库存与地区供货需实际询价
- **优先级:** recommended
- **媒介:** text
- **内容用途:** reference
- **语言:** 英文为主
- **版本或更新情况:** 核对日期2026-09-05；版本信息见具体资料
- **验证日期:** 2026-09-05

**推荐理由:** SEN-21336为Micro版，SEN-21325为较大的标准版；两者不要混买。

**重点:** Required Materials

**局限:** 本轮选Micro版；保留原厂Qwiic线及原理图。

**核验说明:** 核对了型号、对应规格或本地同源代码；本轮选Micro版；保留原厂Qwiic线及原理图。

#### [VL53L8CX Carrier #3419](https://www.pololu.com/product/3419)

- **作者或机构:** Pololu
- **来源渠道:** 厂家规格与手册
- **类型:** 技术参考
- **用途:** 核对所选型号与接口
- **级别:** 工程实施
- **形式:** 网页、图纸或源代码
- **所需时间:** 按所列章节查阅，约5–15分钟
- **适合:** 该部件采购、布板和安装复核
- **获取方式:** 公开资料；采购价格、库存与地区供货需实际询价
- **优先级:** core
- **媒介:** text
- **内容用途:** reference
- **语言:** 英文为主
- **版本或更新情况:** 核对日期2026-09-05；版本信息见具体资料
- **验证日期:** 2026-09-05

**推荐理由:** 约13×23×3mm；3.2–5.5V；峰值150mA；I/O跟随VIN；SPI/I2C脚拉低选择I2C。

**重点:** Features / Connections

**局限:** 本方案VIN固定3.3V；短线连接，勿误用5V逻辑接Radxa。

**核验说明:** 核对了型号、对应规格或本地同源代码；本方案VIN固定3.3V；短线连接，勿误用5V逻辑接Radxa。

#### [AS02008MR-HT-WP](https://puiaudio.com/product/speakers-and-receivers/as02008mr-ht-wp)

- **作者或机构:** PUI Audio
- **来源渠道:** 厂家规格与手册
- **类型:** 技术参考
- **用途:** 核对所选型号与接口
- **级别:** 工程实施
- **形式:** 网页、图纸或源代码
- **所需时间:** 按所列章节查阅，约5–15分钟
- **适合:** 该部件采购、布板和安装复核
- **获取方式:** 公开资料；采购价格、库存与地区供货需实际询价
- **优先级:** recommended
- **媒介:** text
- **内容用途:** reference
- **语言:** 英文为主
- **版本或更新情况:** 核对日期2026-09-05；版本信息见具体资料
- **验证日期:** 2026-09-05

**推荐理由:** 20mm直径、3.9mm高、8Ω、额定1.2W、2.5g。

**重点:** Dimensions & Specifications

**局限:** 与旧20×5占位不同；安装、防漏气及声孔仍要实际验证。

**核验说明:** 核对了型号、对应规格或本地同源代码；与旧20×5占位不同；安装、防漏气及声孔仍要实际验证。

#### [CMC-4015-25T](https://www.sameskydevices.com/product/audio/microphones/electret-condenser-microphones/cmc-4015-25t)

- **作者或机构:** Same Sky
- **来源渠道:** 厂家规格与手册
- **类型:** 技术参考
- **用途:** 核对所选型号与接口
- **级别:** 工程实施
- **形式:** 网页、图纸或源代码
- **所需时间:** 按所列章节查阅，约5–15分钟
- **适合:** 该部件采购、布板和安装复核
- **获取方式:** 公开资料；采购价格、库存与地区供货需实际询价
- **优先级:** recommended
- **媒介:** text
- **内容用途:** reference
- **语言:** 英文为主
- **版本或更新情况:** 核对日期2026-09-05；版本信息见具体资料
- **验证日期:** 2026-09-05

**推荐理由:** 4×4×1.5mm顶入声模拟驻极体，标称3V、负载2.2kΩ。

**重点:** Specifications；datasheet p1

**局限:** 初次搜索的厂家正文与数据表已核对；后续直接抓取出现403。

**核验说明:** 核对了型号、对应规格或本地同源代码；初次搜索的厂家正文与数据表已核对；后续直接抓取出现403。

#### [TLV320AIC3104](https://www.ti.com/lit/ds/symlink/tlv320aic3104.pdf)

- **作者或机构:** Texas Instruments
- **来源渠道:** 厂家规格与手册
- **类型:** 技术参考
- **用途:** 核对所选型号与接口
- **级别:** 工程实施
- **形式:** 网页、图纸或源代码
- **所需时间:** 按所列章节查阅，约5–15分钟
- **适合:** 该部件采购、布板和安装复核
- **获取方式:** 公开资料；采购价格、库存与地区供货需实际询价
- **优先级:** recommended
- **媒介:** text
- **内容用途:** reference
- **语言:** 英文为主
- **版本或更新情况:** 核对日期2026-09-05；版本信息见具体资料
- **验证日期:** 2026-09-05

**推荐理由:** 保留AIC3104的I2S/I2C音频路线；IO/模拟3.3V、内核1.8V；具体供电与时序按数据表。

**重点:** Pin functions / Power / Digital interface

**局限:** 需要PCB与SMT，不是可直接购买的Microduck成品HAT。

**核验说明:** 核对了型号、对应规格或本地同源代码；需要PCB与SMT，不是可直接购买的Microduck成品HAT。

#### [TPA2010D1](https://www.ti.com/lit/ds/symlink/tpa2010d1.pdf)

- **作者或机构:** Texas Instruments
- **来源渠道:** 厂家规格与手册
- **类型:** 技术参考
- **用途:** 核对所选型号与接口
- **级别:** 工程实施
- **形式:** 网页、图纸或源代码
- **所需时间:** 按所列章节查阅，约5–15分钟
- **适合:** 该部件采购、布板和安装复核
- **获取方式:** 公开资料；采购价格、库存与地区供货需实际询价
- **优先级:** recommended
- **媒介:** text
- **内容用途:** reference
- **语言:** 英文为主
- **版本或更新情况:** 核对日期2026-09-05；版本信息见具体资料
- **验证日期:** 2026-09-05

**推荐理由:** TPA2010D1作为5V单声道功放，接AIC3104差分线路输出。

**重点:** Application / Gain setting

**局限:** 限制输出到所选扬声器额定功率以内，回路与麦克风分开。

**核验说明:** 核对了型号、对应规格或本地同源代码；限制输出到所选扬声器额定功率以内，回路与麦克风分开。

#### [S13V30F5 #4082](https://www.pololu.com/product/4082)

- **作者或机构:** Pololu
- **来源渠道:** 厂家规格与手册
- **类型:** 技术参考
- **用途:** 核对所选型号与接口
- **级别:** 工程实施
- **形式:** 网页、图纸或源代码
- **所需时间:** 按所列章节查阅，约5–15分钟
- **适合:** 该部件采购、布板和安装复核
- **获取方式:** 公开资料；采购价格、库存与地区供货需实际询价
- **优先级:** recommended
- **媒介:** text
- **内容用途:** reference
- **语言:** 英文为主
- **版本或更新情况:** 核对日期2026-09-05；版本信息见具体资料
- **验证日期:** 2026-09-05

**推荐理由:** 5V升降压，2.8–22V输入；约22.9×22.9×9.7mm；典型约3A。

**重点:** Features / Output-current graph

**局限:** 实际连续电流受输入电压、散热影响；3A不是无条件保证。

**核验说明:** 核对了型号、对应规格或本地同源代码；实际连续电流受输入电压、散热影响；3A不是无条件保证。

#### [LM74502DDFR](https://www.ti.com/lit/ds/symlink/lm74502.pdf)

- **作者或机构:** Texas Instruments
- **来源渠道:** 厂家规格与手册
- **类型:** 技术参考
- **用途:** 核对所选型号与接口
- **级别:** 工程实施
- **形式:** 网页、图纸或源代码
- **所需时间:** 按所列章节查阅，约5–15分钟
- **适合:** 该部件采购、布板和安装复核
- **获取方式:** 公开资料；采购价格、库存与地区供货需实际询价
- **优先级:** core
- **媒介:** text
- **内容用途:** reference
- **语言:** 英文为主
- **版本或更新情况:** 核对日期2026-09-05；版本信息见具体资料
- **验证日期:** 2026-09-05

**推荐理由:** 3.2–65V控制器，外接共源背靠背NFET；EN/UVLO拉低关断；导通时不提供反向电流阻断。

**重点:** p1 / Pin functions / Typical application

**局限:** 本轮替换原LM74800思路，保留回馈通路；断电后回馈尖峰仍需设计验证。

**核验说明:** 核对了型号、对应规格或本地同源代码；本轮替换原LM74800思路，保留回馈通路；断电后回馈尖峰仍需设计验证。

#### [LM74502 bidirectional current application](https://e2e.ti.com/support/power-management-group/power-management/f/power-management-forum/1503649/lm74502-lm74502-as-high-side-driver-in-back-to-back-connected-com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)

- **作者或机构:** Texas Instruments
- **来源渠道:** 厂家应用支持
- **类型:** 技术参考
- **用途:** 核对所选型号与接口
- **级别:** 工程实施
- **形式:** 网页、图纸或源代码
- **所需时间:** 按所列章节查阅，约5–15分钟
- **适合:** 该部件采购、布板和安装复核
- **获取方式:** 公开资料；采购价格、库存与地区供货需实际询价
- **优先级:** recommended
- **媒介:** text
- **内容用途:** reference
- **语言:** 英文为主
- **版本或更新情况:** 核对日期2026-09-05；版本信息见具体资料
- **验证日期:** 2026-09-05

**推荐理由:** 共源背靠背NFET在控制器有效且栅极导通时允许双向电流。

**重点:** TI工程师答复

**局限:** 属于该电路配置的应用答复，不替代整机回馈测试。

**核验说明:** 核对了型号、对应规格或本地同源代码；属于该电路配置的应用答复，不替代整机回馈测试。

#### [CSD18540Q5B](https://www.ti.com/lit/gpn/CSD18540Q5B)

- **作者或机构:** Texas Instruments
- **来源渠道:** 厂家规格与手册
- **类型:** 技术参考
- **用途:** 核对所选型号与接口
- **级别:** 工程实施
- **形式:** 网页、图纸或源代码
- **所需时间:** 按所列章节查阅，约5–15分钟
- **适合:** 该部件采购、布板和安装复核
- **获取方式:** 公开资料；采购价格、库存与地区供货需实际询价
- **优先级:** recommended
- **媒介:** text
- **内容用途:** reference
- **语言:** 英文为主
- **版本或更新情况:** 核对日期2026-09-05；版本信息见具体资料
- **验证日期:** 2026-09-05

**推荐理由:** 60V NFET，标称5×6mm封装；本方案两颗共源背靠背。

**重点:** Product summary / Package

**局限:** 导通损耗按实际栅压与温度核算，不只引用室温典型电阻。

**核验说明:** 核对了型号、对应规格或本地同源代码；导通损耗按实际栅压与温度核算，不只引用室温典型电阻。

#### [TPS62162DSGR](https://www.ti.com/product/TPS62162/part-details/TPS62162DSGR)

- **作者或机构:** Texas Instruments
- **来源渠道:** 厂家规格与手册
- **类型:** 技术参考
- **用途:** 核对所选型号与接口
- **级别:** 工程实施
- **形式:** 网页、图纸或源代码
- **所需时间:** 按所列章节查阅，约5–15分钟
- **适合:** 该部件采购、布板和安装复核
- **获取方式:** 公开资料；采购价格、库存与地区供货需实际询价
- **优先级:** recommended
- **媒介:** text
- **内容用途:** reference
- **语言:** 英文为主
- **版本或更新情况:** 核对日期2026-09-05；版本信息见具体资料
- **验证日期:** 2026-09-05

**推荐理由:** 3–17V、1A降压器，固定输出版本用于数字3.3V；选DSG封装。

**重点:** Features / Part details

**局限:** 官网直售显示缺货；PCB投产前由SMT供应商确认授权渠道供货。

**核验说明:** 核对了型号、对应规格或本地同源代码；官网直售显示缺货；PCB投产前由SMT供应商确认授权渠道供货。

#### [451/453 Series Nano2 Fuse](https://www.littelfuse.com/assetdocs/fuse-451-and-453-datasheet?assetguid=533cd5cc-956c-4243-867f-6ab5a62f6ba1)

- **作者或机构:** Littelfuse
- **来源渠道:** 厂家规格与手册
- **类型:** 技术参考
- **用途:** 核对所选型号与接口
- **级别:** 工程实施
- **形式:** 网页、图纸或源代码
- **所需时间:** 按所列章节查阅，约5–15分钟
- **适合:** 该部件采购、布板和安装复核
- **获取方式:** 公开资料；采购价格、库存与地区供货需实际询价
- **优先级:** recommended
- **媒介:** text
- **内容用途:** reference
- **语言:** 英文为主
- **版本或更新情况:** 核对日期2026-09-05；版本信息见具体资料
- **验证日期:** 2026-09-05

**推荐理由:** 451系列贴片保险丝，约6.10×2.69×2.69mm；规格覆盖3A、5A和15A。

**重点:** p1–3 电气特性/时间电流曲线/外形

**局限:** 本轮额定值为样机起点；按时间-电流曲线、I²t及线束温升复核，不承担精确电机限流。

**核验说明:** 核对了型号、对应规格或本地同源代码；本轮额定值为样机起点；按时间-电流曲线、I²t及线束温升复核，不承担精确电机限流。

#### [EEUFR1C471](https://industrial.panasonic.com/kr/products/pt/aluminum-cap-lead/models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)

- **作者或机构:** Panasonic
- **来源渠道:** 厂家规格与手册
- **类型:** 技术参考
- **用途:** 核对所选型号与接口
- **级别:** 工程实施
- **形式:** 网页、图纸或源代码
- **所需时间:** 按所列章节查阅，约5–15分钟
- **适合:** 该部件采购、布板和安装复核
- **获取方式:** 公开资料；采购价格、库存与地区供货需实际询价
- **优先级:** recommended
- **媒介:** text
- **内容用途:** reference
- **语言:** 英文为主
- **版本或更新情况:** 核对日期2026-09-05；版本信息见具体资料
- **验证日期:** 2026-09-05

**推荐理由:** FR系列，16V/470µF，直径8mm、长11.5mm。

**重点:** Model table

**局限:** 较旧10mm长度占位增加1.5mm；横置及引脚固定需要重画。

**核验说明:** 核对了型号、对应规格或本地同源代码；较旧10mm长度占位增加1.5mm；横置及引脚固定需要重画。

#### [XA1E-BV302-R](https://www.idec.com/en-us/switches-indicator-lights/switches-pushbuttons/emergency-stop-switches/xa-16mm-estop/xa1e-bv302-r)

- **作者或机构:** IDEC
- **来源渠道:** 厂家规格与手册
- **类型:** 技术参考
- **用途:** 核对所选型号与接口
- **级别:** 工程实施
- **形式:** 网页、图纸或源代码
- **所需时间:** 按所列章节查阅，约5–15分钟
- **适合:** 该部件采购、布板和安装复核
- **获取方式:** 公开资料；采购价格、库存与地区供货需实际询价
- **优先级:** core
- **媒介:** text
- **内容用途:** reference
- **语言:** 英文为主
- **版本或更新情况:** 核对日期2026-09-05；版本信息见具体资料
- **验证日期:** 2026-09-05

**推荐理由:** 16mm安装系列、29mm红蘑菇头、2NC、焊接端子。

**重点:** Key Features / Mechanical Specifications

**局限:** 首版放外置有线盒；开关器件合格不等于整机急停系统认证。

**核验说明:** 核对了型号、对应规格或本地同源代码；首版放外置有线盒；开关器件合格不等于整机急停系统认证。

#### [Grove NFC PN532 113020006](https://www.seeedstudio.com/Grove-NFC.html)

- **作者或机构:** Seeed Studio
- **来源渠道:** 厂家规格与手册
- **类型:** 技术参考
- **用途:** 核对所选型号与接口
- **级别:** 工程实施
- **形式:** 网页、图纸或源代码
- **所需时间:** 按所列章节查阅，约5–15分钟
- **适合:** 该部件采购、布板和安装复核
- **获取方式:** 公开资料；采购价格、库存与地区供货需实际询价
- **优先级:** supplementary
- **媒介:** text
- **内容用途:** reference
- **语言:** 英文为主
- **版本或更新情况:** 核对日期2026-09-05；版本信息见具体资料
- **验证日期:** 2026-09-05

**推荐理由:** 113020006是PN532读卡模块，页面显示有货；不是ST25DV64动态标签。

**重点:** SKU / Product summary

**局限:** 报价/库存会变化；装机需新增NFC程序。

**核验说明:** 核对了型号、对应规格或本地同源代码；报价/库存会变化；装机需新增NFC程序。

#### [Grove NFC Wiki](https://wiki.seeedstudio.com/Grove_NFC/)

- **作者或机构:** Seeed Studio
- **来源渠道:** 厂家规格与手册
- **类型:** 技术参考
- **用途:** 核对所选型号与接口
- **级别:** 工程实施
- **形式:** 网页、图纸或源代码
- **所需时间:** 按所列章节查阅，约5–15分钟
- **适合:** 该部件采购、布板和安装复核
- **获取方式:** 公开资料；采购价格、库存与地区供货需实际询价
- **优先级:** supplementary
- **媒介:** text
- **内容用途:** reference
- **语言:** 英文为主
- **版本或更新情况:** 核对日期2026-09-05；版本信息见具体资料
- **验证日期:** 2026-09-05

**推荐理由:** 控制板25.43×20.35mm、3.3V、UART默认，可连接独立PCB天线。

**重点:** Specifications / Hardware overview

**局限:** 两个模块分别走UART4与UART5；保持原配天线和馈线，不自行裁剪。

**核验说明:** 核对了型号、对应规格或本地同源代码；两个模块分别走UART4与UART5；保持原配天线和馈线，不自行裁剪。

#### [NFC Antenna Dimensions](https://forum.seeedstudio.com/t/nfc-antenna-dimensions/6776)

- **作者或机构:** Seeed Studio 技术支持
- **来源渠道:** 厂家应用支持
- **类型:** 技术参考
- **用途:** 核对所选型号与接口
- **级别:** 工程实施
- **形式:** 网页、图纸或源代码
- **所需时间:** 按所列章节查阅，约5–15分钟
- **适合:** 该部件采购、布板和安装复核
- **获取方式:** 公开资料；采购价格、库存与地区供货需实际询价
- **优先级:** supplementary
- **媒介:** text
- **内容用途:** reference
- **语言:** 英文为主
- **版本或更新情况:** 核对日期2026-09-05；版本信息见具体资料
- **验证日期:** 2026-09-05

**推荐理由:** 配套天线PCB为28×30.5mm；较大尺寸是包装尺寸。

**重点:** 2019-04-26 技术支持回复

**局限:** 以所发模块的配套天线为准，金属与壳体会改变读距。

**核验说明:** 核对了型号、对应规格或本地同源代码；以所发模块的配套天线为准，金属与壳体会改变读距。

#### [B6neo Series](https://www.skyrc.com/b6neo-series)

- **作者或机构:** SkyRC
- **来源渠道:** 厂家规格与手册
- **类型:** 技术参考
- **用途:** 核对所选型号与接口
- **级别:** 工程实施
- **形式:** 网页、图纸或源代码
- **所需时间:** 按所列章节查阅，约5–15分钟
- **适合:** 该部件采购、布板和安装复核
- **获取方式:** 公开资料；采购价格、库存与地区供货需实际询价
- **优先级:** recommended
- **媒介:** text
- **内容用途:** reference
- **语言:** 英文为主
- **版本或更新情况:** 核对日期2026-09-05；版本信息见具体资料
- **验证日期:** 2026-09-05

**推荐理由:** 选择B6neo SK-100198，支持DC/USB-PD输入和平衡充电。

**重点:** 型号表 / Specification

**局限:** 配原厂说明书按标准LiPo 2S设置，非LiHV模式；不在机器人内充电。

**核验说明:** 核对了型号、对应规格或本地同源代码；配原厂说明书按标准LiPo 2S设置，非LiHV模式；不在机器人内充电。

#### [FE-URT-1 Programmer](https://www.feetechrc.com/serial-port-series-steering-gear_50681.html)

- **作者或机构:** FEETECH
- **来源渠道:** 厂家规格与手册
- **类型:** 技术参考
- **用途:** 核对所选型号与接口
- **级别:** 工程实施
- **形式:** 网页、图纸或源代码
- **所需时间:** 按所列章节查阅，约5–15分钟
- **适合:** 该部件采购、布板和安装复核
- **获取方式:** 公开资料；采购价格、库存与地区供货需实际询价
- **优先级:** recommended
- **媒介:** text
- **内容用途:** reference
- **语言:** 英文为主
- **版本或更新情况:** 核对日期2026-09-05；版本信息见具体资料
- **验证日期:** 2026-09-05

**推荐理由:** FE-URT1-C001：USB转TTL/485调试板，52×38.4×16mm，最高1Mbps。

**重点:** FE-URT-1条目

**局限:** 仅台架工具。HD1910的机械参数来自用户附件，不由这个产品页证明。

**核验说明:** 核对了型号、对应规格或本地同源代码；仅台架工具。HD1910的机械参数来自用户附件，不由这个产品页证明。

#### [SSW-120-02-G-D](https://www.samtec.com/products/ssw-120-02-g-d)

- **作者或机构:** Samtec
- **来源渠道:** 厂家规格与手册
- **类型:** 技术参考
- **用途:** 核对所选型号与接口
- **级别:** 工程实施
- **形式:** 网页、图纸或源代码
- **所需时间:** 按所列章节查阅，约5–15分钟
- **适合:** 该部件采购、布板和安装复核
- **获取方式:** 公开资料；采购价格、库存与地区供货需实际询价
- **优先级:** recommended
- **媒介:** text
- **内容用途:** reference
- **语言:** 英文为主
- **版本或更新情况:** 核对日期2026-09-05；版本信息见具体资料
- **验证日期:** 2026-09-05

**推荐理由:** 2.54mm间距，双排40针直插母座。

**重点:** 产品标题/Prints

**局限:** 精确啮合尺寸按配置图；12mm铜柱是设计起点，不是已验收叠高。

**核验说明:** 核对了型号、对应规格或本地同源代码；精确啮合尺寸按配置图；12mm铜柱是设计起点，不是已验收叠高。

#### [Microduck software repository](https://github.com/pollen-robotics/microduck)

- **作者或机构:** Pollen Robotics
- **来源渠道:** 项目源代码
- **类型:** 技术参考
- **用途:** 核对所选型号与接口
- **级别:** 工程实施
- **形式:** 网页、图纸或源代码
- **所需时间:** 按所列章节查阅，约5–15分钟
- **适合:** 该部件采购、布板和安装复核
- **获取方式:** 公开资料；采购价格、库存与地区供货需实际询价
- **优先级:** core
- **媒介:** text
- **内容用途:** reference
- **语言:** 英文为主
- **版本或更新情况:** 核对日期2026-09-05；版本信息见具体资料
- **验证日期:** 2026-09-05

**推荐理由:** 本地运行时要求躯干IMU；旧实现从Dynamixel ID200读取12字节；音频使用aic3104卡名。

**重点:** 本地同源 duck-control/src/imu.rs、bus.rs、deploy/audio/*.dts

**局限:** 采用独立I2C IMU要改RobotIo后端；不是仅插线即可运行。

**核验说明:** 核对了型号、对应规格或本地同源代码；采用独立I2C IMU要改RobotIo后端；不是仅插线即可运行。

#### [Microduck RL repository](https://github.com/pollen-robotics/microduck_rl)

- **作者或机构:** Pollen Robotics
- **来源渠道:** 项目源代码
- **类型:** 技术参考
- **用途:** 核对所选型号与接口
- **级别:** 工程实施
- **形式:** 网页、图纸或源代码
- **所需时间:** 按所列章节查阅，约5–15分钟
- **适合:** 该部件采购、布板和安装复核
- **获取方式:** 公开资料；采购价格、库存与地区供货需实际询价
- **优先级:** supplementary
- **媒介:** text
- **内容用途:** reference
- **语言:** 英文为主
- **版本或更新情况:** 核对日期2026-09-05；版本信息见具体资料
- **验证日期:** 2026-09-05

**推荐理由:** 本地训练传感器引用trunk_base的imu站点，而非head_imu；执行器仍是xl330/m6。

**重点:** 本地 robot_allcollisions.xml 的 sensor/site 与 microduck_constants.py

**局限:** 硬件选型不等于HD电机辨识、策略重训或行走验证。

**核验说明:** 核对了型号、对应规格或本地同源代码；硬件选型不等于HD电机辨识、策略重训或行走验证。

#### [IMX219-160 Camera](https://www.waveshare.com/product/risc-v/cameras/imx219-160-camera.htm)

- **作者或机构:** Waveshare
- **来源渠道:** 厂家规格与手册
- **类型:** 技术参考
- **用途:** 核对所选型号与接口
- **级别:** 工程实施
- **形式:** 网页、图纸或源代码
- **所需时间:** 按所列章节查阅，约5–15分钟
- **适合:** 该部件采购、布板和安装复核
- **获取方式:** 公开资料；采购价格、库存与地区供货需实际询价
- **优先级:** supplementary
- **媒介:** text
- **内容用途:** reference
- **语言:** 英文为主
- **版本或更新情况:** 核对日期2026-09-05；版本信息见具体资料
- **验证日期:** 2026-09-05

**推荐理由:** 非IR的160°版本为25×24mm板框；与32×32mm Radxa模组不同。

**重点:** Specifications / Version Options

**局限:** 本轮不选；若广角优先，需重验FPC、驱动与标定，而非直接沿用原占位。

**核验说明:** 核对了型号、对应规格或本地同源代码；本轮不选；若广角优先，需重验FPC、驱动与标定，而非直接沿用原占位。

#### [USB TO AUDIO](https://www.waveshare.com/product/usb-to-audio.htm)

- **作者或机构:** Waveshare
- **来源渠道:** 厂家规格与手册
- **类型:** 技术参考
- **用途:** 核对所选型号与接口
- **级别:** 工程实施
- **形式:** 网页、图纸或源代码
- **所需时间:** 按所列章节查阅，约5–15分钟
- **适合:** 该部件采购、布板和安装复核
- **获取方式:** 公开资料；采购价格、库存与地区供货需实际询价
- **优先级:** supplementary
- **媒介:** text
- **内容用途:** reference
- **语言:** 英文为主
- **版本或更新情况:** 核对日期2026-09-05；版本信息见具体资料
- **验证日期:** 2026-09-05

**推荐理由:** 现成USB音频模块是一条减少自制音频电路的路线。

**重点:** Product details

**局限:** 本轮不选；机械空间、USB走线和ALSA设备名需另改，不是AIC3104 HAT的直接替身。

**核验说明:** 核对了型号、对应规格或本地同源代码；本轮不选；机械空间、USB走线和ALSA设备名需另改，不是AIC3104 HAT的直接替身。

## 4. 详细学习或探索路线图

<!-- atlas-stage:1 -->
### 阶段 1: 首批采购与资料回执

- **持续时间:** 首轮工程时间盒，采购/打样等待另计
- **每周投入:** 90分钟计划工时
- **必做内容计划用时:** 90 分钟

**目标**

- 带型号与附件版本的首批订单清单

**前置要求**

**指定资源**

- [Gens ace 850mAh 7.4V 2S1P 60C EC2](https://gensace.de/products/gens-ace-850mah-7-4v-2s1p-60c-lipo-battery-pack-with-ec2-plug) — **使用位置:** Product Specs：Capacity、Voltage、C rate、Dimensions、Balance Plug、Discharge Plug; **推荐理由:** GEA8502S60E2；7.4V/850mAh/60C；约58×32×20mm、55g；EC2和JST-XHR-3P。 · **必做**
- [FE-URT-1 Programmer](https://www.feetechrc.com/serial-port-series-steering-gear_50681.html) — **使用位置:** FE-URT-1条目; **推荐理由:** FE-URT1-C001：USB转TTL/485调试板，52×38.4×16mm，最高1Mbps。 · **必做**
- [Radxa Camera 8M 219 Product Brief Rev 1.0](https://dl.radxa.com/accessories/camera-8m-219/radxa_camera_8m_219_product_brief_Revision_1.0.pdf) — **使用位置:** 印刷页5 Physical specifications；页4 FPC; **推荐理由:** 板32±0.2mm见方，孔距28±0.1mm，孔径2±0.1mm；镜头前凸15.98±0.2mm，PCB1.6mm；背面连接器另计。 · **必做**

**学习单元**

- **S11 · 首批采购与资料回执：1** (45 分钟) · **必做**
  - **行动:** 核对25条定选清单与首批数量，取得商家型号/图纸回执。
  - **预期产出:** 带型号与附件版本的首批订单清单子记录1
  - **资源:** [Gens ace 850mAh 7.4V 2S1P 60C EC2](https://gensace.de/products/gens-ace-850mah-7-4v-2s1p-60c-lipo-battery-pack-with-ec2-plug) — Product Specs：Capacity、Voltage、C rate、Dimensions、Balance Plug、Discharge Plug
- **S12 · 首批采购与资料回执：2** (45 分钟) · **必做**
  - **行动:** 保存舵机协议/控制表和同型号CAD；核对电池标准LiPo与EC2。
  - **预期产出:** 带型号与附件版本的首批订单清单子记录2
  - **资源:** [FE-URT-1 Programmer](https://www.feetechrc.com/serial-port-series-steering-gear_50681.html) — FE-URT-1条目

**阶段产出:** 带型号与附件版本的首批订单清单

**产出模板**

- 型号/版本
- 测试条件
- 实测数值/波形/尺寸
- 通过依据
- 需要修改的电路或零件及复测条件

**完成标准**

- 有可复核的记录，而非仅写完成。
- 前置证据缺失时，不把该环节标记为通过。

**自检问题**

- 把资料参数、设计假设和实测结果分开了吗？
- 下一环节是否真的具备输入？

**最小可行路径**

- S11
- S12

**卡住时怎么办**

- 资料缺失时先推进独立的机械/主控验证，不猜测寄存器、线序或连续负载。
- 实测失败则只修改相关电路/零件并回归测试。

**可选分支**

- 扩展测试和返工所需时间另计。

<!-- /atlas-stage -->

<!-- atlas-stage:2 -->
### 阶段 2: 单舵机和主控台架

- **持续时间:** 首轮工程时间盒，采购/打样等待另计
- **每周投入:** 180分钟计划工时
- **必做内容计划用时:** 180 分钟

**目标**

- 单舵机与IMU数据日志

**前置要求**

- 阶段1的相关输入具备

**指定资源**

- [FE-URT-1 Programmer](https://www.feetechrc.com/serial-port-series-steering-gear_50681.html) — **使用位置:** FE-URT-1条目; **推荐理由:** FE-URT1-C001：USB转TTL/485调试板，52×38.4×16mm，最高1Mbps。 · **必做**
- [Microduck software repository](https://github.com/pollen-robotics/microduck) — **使用位置:** 本地同源 duck-control/src/imu.rs、bus.rs、deploy/audio/*.dts; **推荐理由:** 本地运行时要求躯干IMU；旧实现从Dynamixel ID200读取12字节；音频使用aic3104卡名。 · **必做**
- [LSM6DSV16X Hardware Overview](https://docs.sparkfun.com/SparkFun_6DoF_LSM6DSV16X/hardware_overview/) — **使用位置:** Board Outline / I2C / Power; **推荐理由:** Micro版SEN-21336为0.3×0.75英寸，即7.62×19.05mm；I2C默认0x6B；3.3V使用。 · **必做**

**学习单元**

- **S21 · 单舵机和主控台架：1** (90 分钟) · **必做**
  - **行动:** 先在6V限流台架进行舵机空载通信与机械试装；承载试验待真实额定工况确认。
  - **预期产出:** 单舵机与IMU数据日志子记录1
  - **资源:** [FE-URT-1 Programmer](https://www.feetechrc.com/serial-port-series-steering-gear_50681.html) — FE-URT-1条目
- **S22 · 单舵机和主控台架：2** (90 分钟) · **必做**
  - **行动:** 启动Radxa，处理UART2控制台；验证IMU身份、轴向、数据新鲜度。
  - **预期产出:** 单舵机与IMU数据日志子记录2
  - **资源:** [Microduck software repository](https://github.com/pollen-robotics/microduck) — 本地同源 duck-control/src/imu.rs、bus.rs、deploy/audio/*.dts

**阶段产出:** 单舵机与IMU数据日志

**产出模板**

- 型号/版本
- 测试条件
- 实测数值/波形/尺寸
- 通过依据
- 需要修改的电路或零件及复测条件

**完成标准**

- 有可复核的记录，而非仅写完成。
- 前置证据缺失时，不把该环节标记为通过。

**自检问题**

- 把资料参数、设计假设和实测结果分开了吗？
- 下一环节是否真的具备输入？

**最小可行路径**

- S21
- S22

**卡住时怎么办**

- 资料缺失时先推进独立的机械/主控验证，不猜测寄存器、线序或连续负载。
- 实测失败则只修改相关电路/零件并回归测试。

**可选分支**

- 扩展测试和返工所需时间另计。

<!-- /atlas-stage -->

<!-- atlas-stage:3 -->
### 阶段 3: 真实器件的机械占位

- **持续时间:** 首轮工程时间盒，采购/打样等待另计
- **每周投入:** 240分钟计划工时
- **必做内容计划用时:** 240 分钟

**目标**

- RA3占位模型与试配尺寸表

**前置要求**

- 阶段2的相关输入具备

**指定资源**

- [Radxa Camera 8M 219 Product Brief Rev 1.0](https://dl.radxa.com/accessories/camera-8m-219/radxa_camera_8m_219_product_brief_Revision_1.0.pdf) — **使用位置:** 印刷页5 Physical specifications；页4 FPC; **推荐理由:** 板32±0.2mm见方，孔距28±0.1mm，孔径2±0.1mm；镜头前凸15.98±0.2mm，PCB1.6mm；背面连接器另计。 · **必做**
- [Radxa Heatsink 5519A](https://radxa.com/products/accessories/heatsink-5519a/) — **使用位置:** 适配机型; **推荐理由:** 5519A为ZERO 3W/3E配套散热器。 · **必做**
- [Gens ace 850mAh 7.4V 2S1P 60C EC2](https://gensace.de/products/gens-ace-850mah-7-4v-2s1p-60c-lipo-battery-pack-with-ec2-plug) — **使用位置:** Product Specs：Capacity、Voltage、C rate、Dimensions、Balance Plug、Discharge Plug; **推荐理由:** GEA8502S60E2；7.4V/850mAh/60C；约58×32×20mm、55g；EC2和JST-XHR-3P。 · **必做**

**学习单元**

- **S31 · 真实器件的机械占位：1** (120 分钟) · **必做**
  - **行动:** 用到货尺寸/CAD更新电池、相机、散热器、排针及线束的包络。
  - **预期产出:** RA3占位模型与试配尺寸表子记录1
  - **资源:** [Radxa Camera 8M 219 Product Brief Rev 1.0](https://dl.radxa.com/accessories/camera-8m-219/radxa_camera_8m_219_product_brief_Revision_1.0.pdf) — 印刷页5 Physical specifications；页4 FPC
- **S32 · 真实器件的机械占位：2** (120 分钟) · **必做**
  - **行动:** 打印小试配件；记录孔位、螺钉、插拔与线头所需余量。
  - **预期产出:** RA3占位模型与试配尺寸表子记录2
  - **资源:** [Radxa Heatsink 5519A](https://radxa.com/products/accessories/heatsink-5519a/) — 适配机型

**阶段产出:** RA3占位模型与试配尺寸表

**产出模板**

- 型号/版本
- 测试条件
- 实测数值/波形/尺寸
- 通过依据
- 需要修改的电路或零件及复测条件

**完成标准**

- 有可复核的记录，而非仅写完成。
- 前置证据缺失时，不把该环节标记为通过。

**自检问题**

- 把资料参数、设计假设和实测结果分开了吗？
- 下一环节是否真的具备输入？

**最小可行路径**

- S31
- S32

**卡住时怎么办**

- 资料缺失时先推进独立的机械/主控验证，不猜测寄存器、线序或连续负载。
- 实测失败则只修改相关电路/零件并回归测试。

**可选分支**

- 扩展测试和返工所需时间另计。

<!-- /atlas-stage -->

<!-- atlas-stage:4 -->
### 阶段 4: 两块PCB首轮设计

- **持续时间:** 首轮工程时间盒，采购/打样等待另计
- **每周投入:** 720分钟计划工时
- **必做内容计划用时:** 720 分钟

**目标**

- 原理图、PCB、Gerber、BOM与贴片坐标

**前置要求**

- 阶段3的相关输入具备

**指定资源**

- [LM74502DDFR](https://www.ti.com/lit/ds/symlink/lm74502.pdf) — **使用位置:** p1 / Pin functions / Typical application; **推荐理由:** 3.2–65V控制器，外接共源背靠背NFET；EN/UVLO拉低关断；导通时不提供反向电流阻断。 · **必做**
- [TLV320AIC3104](https://www.ti.com/lit/ds/symlink/tlv320aic3104.pdf) — **使用位置:** Pin functions / Power / Digital interface; **推荐理由:** 保留AIC3104的I2S/I2C音频路线；IO/模拟3.3V、内核1.8V；具体供电与时序按数据表。 · **必做**
- [451/453 Series Nano2 Fuse](https://www.littelfuse.com/assetdocs/fuse-451-and-453-datasheet?assetguid=533cd5cc-956c-4243-867f-6ab5a62f6ba1) — **使用位置:** p1–3 电气特性/时间电流曲线/外形; **推荐理由:** 451系列贴片保险丝，约6.10×2.69×2.69mm；规格覆盖3A、5A和15A。 · **必做**

**学习单元**

- **S41 · 两块PCB首轮设计：1** (360 分钟) · **必做**
  - **行动:** 按配电/音频架构完成原理图、网表和ERC；补上UVLO/回馈/手动ARM电路。
  - **预期产出:** 原理图、PCB、Gerber、BOM与贴片坐标子记录1
  - **资源:** [LM74502DDFR](https://www.ti.com/lit/ds/symlink/lm74502.pdf) — p1 / Pin functions / Typical application
- **S42 · 两块PCB首轮设计：2** (360 分钟) · **必做**
  - **行动:** 完成布板、制造检查和3D装配复核，提交板厂PCB及SMT资料。
  - **预期产出:** 原理图、PCB、Gerber、BOM与贴片坐标子记录2
  - **资源:** [TLV320AIC3104](https://www.ti.com/lit/ds/symlink/tlv320aic3104.pdf) — Pin functions / Power / Digital interface

**阶段产出:** 原理图、PCB、Gerber、BOM与贴片坐标

**产出模板**

- 型号/版本
- 测试条件
- 实测数值/波形/尺寸
- 通过依据
- 需要修改的电路或零件及复测条件

**完成标准**

- 有可复核的记录，而非仅写完成。
- 前置证据缺失时，不把该环节标记为通过。

**自检问题**

- 把资料参数、设计假设和实测结果分开了吗？
- 下一环节是否真的具备输入？

**最小可行路径**

- S41
- S42

**卡住时怎么办**

- 资料缺失时先推进独立的机械/主控验证，不猜测寄存器、线序或连续负载。
- 实测失败则只修改相关电路/零件并回归测试。

**可选分支**

- 扩展测试和返工所需时间另计。

<!-- /atlas-stage -->

<!-- atlas-stage:5 -->
### 阶段 5: 电气与多模块联调

- **持续时间:** 首轮工程时间盒，采购/打样等待另计
- **每周投入:** 420分钟计划工时
- **必做内容计划用时:** 420 分钟

**目标**

- 电源与传感器联调报告

**前置要求**

- 阶段4的相关输入具备

**指定资源**

- [S13V30F5 #4082](https://www.pololu.com/product/4082) — **使用位置:** Features / Output-current graph; **推荐理由:** 5V升降压，2.8–22V输入；约22.9×22.9×9.7mm；典型约3A。 · **必做**
- [Radxa Camera 8M 219](https://docs.radxa.com/en/accessories/camera/camera-8m-219) — **使用位置:** Default FPC / FPC Cable; **推荐理由:** 原配150mm同面22P 0.5mm转15P 1.0mm，官方明确支持ZERO 3W/3E。 · **必做**
- [Grove NFC Wiki](https://wiki.seeedstudio.com/Grove_NFC/) — **使用位置:** Specifications / Hardware overview; **推荐理由:** 控制板25.43×20.35mm、3.3V、UART默认，可连接独立PCB天线。 · **必做**

**学习单元**

- **S51 · 电气与多模块联调：1** (210 分钟) · **必做**
  - **行动:** 记录5V输出、启动浪涌、母线回馈、线束温升，验证急停及复位不会自行恢复运动。
  - **预期产出:** 电源与传感器联调报告子记录1
  - **资源:** [S13V30F5 #4082](https://www.pololu.com/product/4082) — Features / Output-current graph
- **S52 · 电气与多模块联调：2** (210 分钟) · **必做**
  - **行动:** 逐项完成摄像、录放音、测距、IMU和NFC，再检查并发通信与50Hz控制时间。
  - **预期产出:** 电源与传感器联调报告子记录2
  - **资源:** [Radxa Camera 8M 219](https://docs.radxa.com/en/accessories/camera/camera-8m-219) — Default FPC / FPC Cable

**阶段产出:** 电源与传感器联调报告

**产出模板**

- 型号/版本
- 测试条件
- 实测数值/波形/尺寸
- 通过依据
- 需要修改的电路或零件及复测条件

**完成标准**

- 有可复核的记录，而非仅写完成。
- 前置证据缺失时，不把该环节标记为通过。

**自检问题**

- 把资料参数、设计假设和实测结果分开了吗？
- 下一环节是否真的具备输入？

**最小可行路径**

- S51
- S52

**卡住时怎么办**

- 资料缺失时先推进独立的机械/主控验证，不猜测寄存器、线序或连续负载。
- 实测失败则只修改相关电路/零件并回归测试。

**可选分支**

- 扩展测试和返工所需时间另计。

<!-- /atlas-stage -->

<!-- atlas-stage:6 -->
### 阶段 6: 单腿到整机放行复核

- **持续时间:** 首轮工程时间盒，采购/打样等待另计
- **每周投入:** 240分钟计划工时
- **必做内容计划用时:** 240 分钟

**目标**

- 明确已通过/待返工的制造清单

**前置要求**

- 阶段5的相关输入具备

**指定资源**

- [Microduck software repository](https://github.com/pollen-robotics/microduck) — **使用位置:** 本地同源 duck-control/src/imu.rs、bus.rs、deploy/audio/*.dts; **推荐理由:** 本地运行时要求躯干IMU；旧实现从Dynamixel ID200读取12字节；音频使用aic3104卡名。 · **必做**
- [Microduck RL repository](https://github.com/pollen-robotics/microduck_rl) — **使用位置:** 本地 robot_allcollisions.xml 的 sensor/site 与 microduck_constants.py; **推荐理由:** 本地训练传感器引用trunk_base的imu站点，而非head_imu；执行器仍是xl330/m6。 · **必做**
- [Gens ace 850mAh 7.4V 2S1P 60C EC2](https://gensace.de/products/gens-ace-850mah-7-4v-2s1p-60c-lipo-battery-pack-with-ec2-plug) — **使用位置:** Product Specs：Capacity、Voltage、C rate、Dimensions、Balance Plug、Discharge Plug; **推荐理由:** GEA8502S60E2；7.4V/850mAh/60C；约58×32×20mm、55g；EC2和JST-XHR-3P。 · **必做**

**学习单元**

- **S61 · 单腿到整机放行复核：1** (120 分钟) · **必做**
  - **行动:** 完成单腿承载、全角度走线检查；实测舵机参数并更新质量/惯量。
  - **预期产出:** 明确已通过/待返工的制造清单子记录1
  - **资源:** [Microduck software repository](https://github.com/pollen-robotics/microduck) — 本地同源 duck-control/src/imu.rs、bus.rs、deploy/audio/*.dts
- **S62 · 单腿到整机放行复核：2** (120 分钟) · **必做**
  - **行动:** 逐件审核RA3打印清单；整机与步态验证没有通过的项目继续保留开放。
  - **预期产出:** 明确已通过/待返工的制造清单子记录2
  - **资源:** [Microduck RL repository](https://github.com/pollen-robotics/microduck_rl) — 本地 robot_allcollisions.xml 的 sensor/site 与 microduck_constants.py

**阶段产出:** 明确已通过/待返工的制造清单

**产出模板**

- 型号/版本
- 测试条件
- 实测数值/波形/尺寸
- 通过依据
- 需要修改的电路或零件及复测条件

**完成标准**

- 有可复核的记录，而非仅写完成。
- 前置证据缺失时，不把该环节标记为通过。

**自检问题**

- 把资料参数、设计假设和实测结果分开了吗？
- 下一环节是否真的具备输入？

**最小可行路径**

- S61
- S62

**卡住时怎么办**

- 资料缺失时先推进独立的机械/主控验证，不猜测寄存器、线序或连续负载。
- 实测失败则只修改相关电路/零件并回归测试。

**可选分支**

- 扩展测试和返工所需时间另计。

<!-- /atlas-stage -->

## 5. 资源出处

### 证据说明

<!-- atlas-evidence:1 -->

#### E_battery · GEA8502S60E2；7.4V/850mAh/60C；约58×32×20mm、55g；EC2和JST-XHR-3P。

- **判断类型:** fact
- **可信度:** high
- **信息截至:** 2026-09-05
- **核验说明:** 网页库存标记混杂，尺寸为约值；C数是厂家标称而非本机实测。

- [Gens ace 850mAh 7.4V 2S1P 60C EC2](https://gensace.de/products/gens-ace-850mah-7-4v-2s1p-60c-lipo-battery-pack-with-ec2-plug) — Product Specs：Capacity、Voltage、C rate、Dimensions、Balance Plug、Discharge Plug

<!-- /atlas-evidence -->

<!-- atlas-evidence:2 -->

#### E_radxa · RK3566；可选eMMC与40针排针；22针0.5mm CSI；官方列出配套散热器和相机。

- **判断类型:** fact
- **可信度:** high
- **信息截至:** 2026-09-05
- **核验说明:** 具体内存/eMMC和PCB版本以订货回执与丝印为准。

- [Radxa ZERO 3W](https://radxa.com/products/zeros/zero3w/) — 接口与配件

<!-- /atlas-evidence -->

<!-- atlas-evidence:3 -->

#### E_radxa_versions · V1.11与V1.12(AIC8800)分别提供图纸；旧3D文件不自动证明新板元件高度一致。

- **判断类型:** fact
- **可信度:** high
- **信息截至:** 2026-09-05
- **核验说明:** 本地旧STEP有效性问题未在本轮消除。

- [ZERO 3 Hardware Design Downloads](https://docs.radxa.com/en/zero/zero3/download) — Hardware Design

<!-- /atlas-evidence -->

<!-- atlas-evidence:4 -->

#### E_gpio · GPIO为3.3V；UART2占8/10；I2C4占27/28；UART4占16/18；UART5占32/33。

- **判断类型:** fact
- **可信度:** high
- **信息截至:** 2026-09-05
- **核验说明:** UART2默认兼任控制台；需处理启动日志与引导输入。

- [ZERO 3 Hardware Interface](https://docs.radxa.com/en/zero/zero3/hardware-design/hardware-interface) — 40 PIN GPIO / Debug Serial / MIPI CSI

<!-- /atlas-evidence -->

<!-- atlas-evidence:5 -->

#### E_heat · 5519A为ZERO 3W/3E配套散热器。

- **判断类型:** fact
- **可信度:** high
- **信息截至:** 2026-09-05
- **核验说明:** 官网正文未列完整高度，本轮不虚构其包络；到货或有效CAD后复核叠高。

- [Radxa Heatsink 5519A](https://radxa.com/products/accessories/heatsink-5519a/) — 适配机型

<!-- /atlas-evidence -->

<!-- atlas-evidence:6 -->

#### E_camera · 板32±0.2mm见方，孔距28±0.1mm，孔径2±0.1mm；镜头前凸15.98±0.2mm，PCB1.6mm；背面连接器另计。

- **判断类型:** fact
- **可信度:** high
- **信息截至:** 2026-09-05
- **核验说明:** 前凸尺寸不是整个模组总厚；旧25×24占位和M12镜头座需要改。

- [Radxa Camera 8M 219 Product Brief Rev 1.0](https://dl.radxa.com/accessories/camera-8m-219/radxa_camera_8m_219_product_brief_Revision_1.0.pdf) — 印刷页5 Physical specifications；页4 FPC

<!-- /atlas-evidence -->

<!-- atlas-evidence:7 -->

#### E_camera_cable · 原配150mm同面22P 0.5mm转15P 1.0mm，官方明确支持ZERO 3W/3E。

- **判断类型:** fact
- **可信度:** high
- **信息截至:** 2026-09-05
- **核验说明:** 资料同时出现不同视角口径，按D74/H62/V49作初始标定参考，最终重标定。

- [Radxa Camera 8M 219](https://docs.radxa.com/en/accessories/camera/camera-8m-219) — Default FPC / FPC Cable

<!-- /atlas-evidence -->

<!-- atlas-evidence:8 -->

#### E_imu · Micro版SEN-21336为0.3×0.75英寸，即7.62×19.05mm；I2C默认0x6B；3.3V使用。

- **判断类型:** fact
- **可信度:** high
- **信息截至:** 2026-09-05
- **核验说明:** 模组不是Dynamixel ID200设备；需要新的I2C读取后端。

- [LSM6DSV16X Hardware Overview](https://docs.sparkfun.com/SparkFun_6DoF_LSM6DSV16X/hardware_overview/) — Board Outline / I2C / Power

<!-- /atlas-evidence -->

<!-- atlas-evidence:9 -->

#### E_imu_product · SEN-21336为Micro版，SEN-21325为较大的标准版；两者不要混买。

- **判断类型:** fact
- **可信度:** high
- **信息截至:** 2026-09-05
- **核验说明:** 本轮选Micro版；保留原厂Qwiic线及原理图。

- [SparkFun LSM6DSV16X Hookup Guide](https://docs.sparkfun.com/SparkFun_6DoF_LSM6DSV16X/) — Required Materials

<!-- /atlas-evidence -->

<!-- atlas-evidence:10 -->

#### E_tof · 约13×23×3mm；3.2–5.5V；峰值150mA；I/O跟随VIN；SPI/I2C脚拉低选择I2C。

- **判断类型:** fact
- **可信度:** high
- **信息截至:** 2026-09-05
- **核验说明:** 本方案VIN固定3.3V；短线连接，勿误用5V逻辑接Radxa。

- [VL53L8CX Carrier #3419](https://www.pololu.com/product/3419) — Features / Connections

<!-- /atlas-evidence -->

<!-- atlas-evidence:11 -->

#### E_speaker · 20mm直径、3.9mm高、8Ω、额定1.2W、2.5g。

- **判断类型:** fact
- **可信度:** high
- **信息截至:** 2026-09-05
- **核验说明:** 与旧20×5占位不同；安装、防漏气及声孔仍要实际验证。

- [AS02008MR-HT-WP](https://puiaudio.com/product/speakers-and-receivers/as02008mr-ht-wp) — Dimensions & Specifications

<!-- /atlas-evidence -->

<!-- atlas-evidence:12 -->

#### E_mic · 4×4×1.5mm顶入声模拟驻极体，标称3V、负载2.2kΩ。

- **判断类型:** fact
- **可信度:** medium
- **信息截至:** 2026-09-05
- **核验说明:** 初次搜索的厂家正文与数据表已核对；后续直接抓取出现403。

- [CMC-4015-25T](https://www.sameskydevices.com/product/audio/microphones/electret-condenser-microphones/cmc-4015-25t) — Specifications；datasheet p1

<!-- /atlas-evidence -->

<!-- atlas-evidence:13 -->

#### E_codec · 保留AIC3104的I2S/I2C音频路线；IO/模拟3.3V、内核1.8V；具体供电与时序按数据表。

- **判断类型:** fact
- **可信度:** high
- **信息截至:** 2026-09-05
- **核验说明:** 需要PCB与SMT，不是可直接购买的Microduck成品HAT。

- [TLV320AIC3104](https://www.ti.com/lit/ds/symlink/tlv320aic3104.pdf) — Pin functions / Power / Digital interface

<!-- /atlas-evidence -->

<!-- atlas-evidence:14 -->

#### E_amp · TPA2010D1作为5V单声道功放，接AIC3104差分线路输出。

- **判断类型:** fact
- **可信度:** high
- **信息截至:** 2026-09-05
- **核验说明:** 限制输出到所选扬声器额定功率以内，回路与麦克风分开。

- [TPA2010D1](https://www.ti.com/lit/ds/symlink/tpa2010d1.pdf) — Application / Gain setting

<!-- /atlas-evidence -->

<!-- atlas-evidence:15 -->

#### E_buck · 5V升降压，2.8–22V输入；约22.9×22.9×9.7mm；典型约3A。

- **判断类型:** fact
- **可信度:** high
- **信息截至:** 2026-09-05
- **核验说明:** 实际连续电流受输入电压、散热影响；3A不是无条件保证。

- [S13V30F5 #4082](https://www.pololu.com/product/4082) — Features / Output-current graph

<!-- /atlas-evidence -->

<!-- atlas-evidence:16 -->

#### E_power · 3.2–65V控制器，外接共源背靠背NFET；EN/UVLO拉低关断；导通时不提供反向电流阻断。

- **判断类型:** fact
- **可信度:** high
- **信息截至:** 2026-09-05
- **核验说明:** 本轮替换原LM74800思路，保留回馈通路；断电后回馈尖峰仍需设计验证。

- [LM74502DDFR](https://www.ti.com/lit/ds/symlink/lm74502.pdf) — p1 / Pin functions / Typical application

<!-- /atlas-evidence -->

<!-- atlas-evidence:17 -->

#### E_power_reverse · 共源背靠背NFET在控制器有效且栅极导通时允许双向电流。

- **判断类型:** fact
- **可信度:** high
- **信息截至:** 2026-09-05
- **核验说明:** 属于该电路配置的应用答复，不替代整机回馈测试。

- [LM74502 bidirectional current application](https://e2e.ti.com/support/power-management-group/power-management/f/power-management-forum/1503649/lm74502-lm74502-as-high-side-driver-in-back-to-back-connected-com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) — TI工程师答复

<!-- /atlas-evidence -->

<!-- atlas-evidence:18 -->

#### E_fet · 60V NFET，标称5×6mm封装；本方案两颗共源背靠背。

- **判断类型:** fact
- **可信度:** high
- **信息截至:** 2026-09-05
- **核验说明:** 导通损耗按实际栅压与温度核算，不只引用室温典型电阻。

- [CSD18540Q5B](https://www.ti.com/lit/gpn/CSD18540Q5B) — Product summary / Package

<!-- /atlas-evidence -->

<!-- atlas-evidence:19 -->

#### E_digital_supply · 3–17V、1A降压器，固定输出版本用于数字3.3V；选DSG封装。

- **判断类型:** fact
- **可信度:** high
- **信息截至:** 2026-09-05
- **核验说明:** 官网直售显示缺货；PCB投产前由SMT供应商确认授权渠道供货。

- [TPS62162DSGR](https://www.ti.com/product/TPS62162/part-details/TPS62162DSGR) — Features / Part details

<!-- /atlas-evidence -->

<!-- atlas-evidence:20 -->

#### E_fuse · 451系列贴片保险丝，约6.10×2.69×2.69mm；规格覆盖3A、5A和15A。

- **判断类型:** fact
- **可信度:** high
- **信息截至:** 2026-09-05
- **核验说明:** 本轮额定值为样机起点；按时间-电流曲线、I²t及线束温升复核，不承担精确电机限流。

- [451/453 Series Nano2 Fuse](https://www.littelfuse.com/assetdocs/fuse-451-and-453-datasheet?assetguid=533cd5cc-956c-4243-867f-6ab5a62f6ba1) — p1–3 电气特性/时间电流曲线/外形

<!-- /atlas-evidence -->

<!-- atlas-evidence:21 -->

#### E_cap · FR系列，16V/470µF，直径8mm、长11.5mm。

- **判断类型:** fact
- **可信度:** high
- **信息截至:** 2026-09-05
- **核验说明:** 较旧10mm长度占位增加1.5mm；横置及引脚固定需要重画。

- [EEUFR1C471](https://industrial.panasonic.com/kr/products/pt/aluminum-cap-lead/models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) — Model table

<!-- /atlas-evidence -->

<!-- atlas-evidence:22 -->

#### E_estop · 16mm安装系列、29mm红蘑菇头、2NC、焊接端子。

- **判断类型:** fact
- **可信度:** high
- **信息截至:** 2026-09-05
- **核验说明:** 首版放外置有线盒；开关器件合格不等于整机急停系统认证。

- [XA1E-BV302-R](https://www.idec.com/en-us/switches-indicator-lights/switches-pushbuttons/emergency-stop-switches/xa-16mm-estop/xa1e-bv302-r) — Key Features / Mechanical Specifications

<!-- /atlas-evidence -->

<!-- atlas-evidence:23 -->

#### E_nfc · 113020006是PN532读卡模块，页面显示有货；不是ST25DV64动态标签。

- **判断类型:** fact
- **可信度:** high
- **信息截至:** 2026-09-05
- **核验说明:** 报价/库存会变化；装机需新增NFC程序。

- [Grove NFC PN532 113020006](https://www.seeedstudio.com/Grove-NFC.html) — SKU / Product summary

<!-- /atlas-evidence -->

<!-- atlas-evidence:24 -->

#### E_nfc_wiring · 控制板25.43×20.35mm、3.3V、UART默认，可连接独立PCB天线。

- **判断类型:** fact
- **可信度:** high
- **信息截至:** 2026-09-05
- **核验说明:** 两个模块分别走UART4与UART5；保持原配天线和馈线，不自行裁剪。

- [Grove NFC Wiki](https://wiki.seeedstudio.com/Grove_NFC/) — Specifications / Hardware overview

<!-- /atlas-evidence -->

<!-- atlas-evidence:25 -->

#### E_nfc_antenna · 配套天线PCB为28×30.5mm；较大尺寸是包装尺寸。

- **判断类型:** fact
- **可信度:** high
- **信息截至:** 2026-09-05
- **核验说明:** 以所发模块的配套天线为准，金属与壳体会改变读距。

- [NFC Antenna Dimensions](https://forum.seeedstudio.com/t/nfc-antenna-dimensions/6776) — 2019-04-26 技术支持回复

<!-- /atlas-evidence -->

<!-- atlas-evidence:26 -->

#### E_charger · 选择B6neo SK-100198，支持DC/USB-PD输入和平衡充电。

- **判断类型:** fact
- **可信度:** high
- **信息截至:** 2026-09-05
- **核验说明:** 配原厂说明书按标准LiPo 2S设置，非LiHV模式；不在机器人内充电。

- [B6neo Series](https://www.skyrc.com/b6neo-series) — 型号表 / Specification

<!-- /atlas-evidence -->

<!-- atlas-evidence:27 -->

#### E_debug · FE-URT1-C001：USB转TTL/485调试板，52×38.4×16mm，最高1Mbps。

- **判断类型:** fact
- **可信度:** high
- **信息截至:** 2026-09-05
- **核验说明:** 仅台架工具。HD1910的机械参数来自用户附件，不由这个产品页证明。

- [FE-URT-1 Programmer](https://www.feetechrc.com/serial-port-series-steering-gear_50681.html) — FE-URT-1条目

<!-- /atlas-evidence -->

<!-- atlas-evidence:28 -->

#### E_header · 2.54mm间距，双排40针直插母座。

- **判断类型:** fact
- **可信度:** high
- **信息截至:** 2026-09-05
- **核验说明:** 精确啮合尺寸按配置图；12mm铜柱是设计起点，不是已验收叠高。

- [SSW-120-02-G-D](https://www.samtec.com/products/ssw-120-02-g-d) — 产品标题/Prints

<!-- /atlas-evidence -->

<!-- atlas-evidence:29 -->

#### E_runtime · 本地运行时要求躯干IMU；旧实现从Dynamixel ID200读取12字节；音频使用aic3104卡名。

- **判断类型:** fact
- **可信度:** high
- **信息截至:** 2026-09-05
- **核验说明:** 采用独立I2C IMU要改RobotIo后端；不是仅插线即可运行。

- [Microduck software repository](https://github.com/pollen-robotics/microduck) — 本地同源 duck-control/src/imu.rs、bus.rs、deploy/audio/*.dts

<!-- /atlas-evidence -->

<!-- atlas-evidence:30 -->

#### E_rl · 本地训练传感器引用trunk_base的imu站点，而非head_imu；执行器仍是xl330/m6。

- **判断类型:** fact
- **可信度:** high
- **信息截至:** 2026-09-05
- **核验说明:** 硬件选型不等于HD电机辨识、策略重训或行走验证。

- [Microduck RL repository](https://github.com/pollen-robotics/microduck_rl) — 本地 robot_allcollisions.xml 的 sensor/site 与 microduck_constants.py

<!-- /atlas-evidence -->

<!-- atlas-evidence:31 -->

#### E_alt_camera · 非IR的160°版本为25×24mm板框；与32×32mm Radxa模组不同。

- **判断类型:** fact
- **可信度:** high
- **信息截至:** 2026-09-05
- **核验说明:** 本轮不选；若广角优先，需重验FPC、驱动与标定，而非直接沿用原占位。

- [IMX219-160 Camera](https://www.waveshare.com/product/risc-v/cameras/imx219-160-camera.htm) — Specifications / Version Options

<!-- /atlas-evidence -->

<!-- atlas-evidence:32 -->

#### E_alt_audio · 现成USB音频模块是一条减少自制音频电路的路线。

- **判断类型:** fact
- **可信度:** high
- **信息截至:** 2026-09-05
- **核验说明:** 本轮不选；机械空间、USB走线和ALSA设备名需另改，不是AIC3104 HAT的直接替身。

- [USB TO AUDIO](https://www.waveshare.com/product/usb-to-audio.htm) — Product details

<!-- /atlas-evidence -->

**资源筛选说明:** 商业规格能支持型号和参数，不等于本机实测性能；附件与本地代码核验另记在项目数据中。

<!-- atlas-source:1 -->
### 厂家规格与手册

按文中定位查阅并核对版本。

- [Gens ace 850mAh 7.4V 2S1P 60C EC2](https://gensace.de/products/gens-ace-850mah-7-4v-2s1p-60c-lipo-battery-pack-with-ec2-plug) — Gens ace; Product Specs：Capacity、Voltage、C rate、Dimensions、Balance Plug、Discharge Plug
- [Radxa ZERO 3W](https://radxa.com/products/zeros/zero3w/) — Radxa; 接口与配件
- [ZERO 3 Hardware Design Downloads](https://docs.radxa.com/en/zero/zero3/download) — Radxa; Hardware Design
- [ZERO 3 Hardware Interface](https://docs.radxa.com/en/zero/zero3/hardware-design/hardware-interface) — Radxa; 40 PIN GPIO / Debug Serial / MIPI CSI
- [Radxa Heatsink 5519A](https://radxa.com/products/accessories/heatsink-5519a/) — Radxa; 适配机型
- [Radxa Camera 8M 219 Product Brief Rev 1.0](https://dl.radxa.com/accessories/camera-8m-219/radxa_camera_8m_219_product_brief_Revision_1.0.pdf) — Radxa; 印刷页5 Physical specifications；页4 FPC
- [Radxa Camera 8M 219](https://docs.radxa.com/en/accessories/camera/camera-8m-219) — Radxa; Default FPC / FPC Cable
- [LSM6DSV16X Hardware Overview](https://docs.sparkfun.com/SparkFun_6DoF_LSM6DSV16X/hardware_overview/) — SparkFun; Board Outline / I2C / Power
- [SparkFun LSM6DSV16X Hookup Guide](https://docs.sparkfun.com/SparkFun_6DoF_LSM6DSV16X/) — SparkFun; Required Materials
- [VL53L8CX Carrier #3419](https://www.pololu.com/product/3419) — Pololu; Features / Connections
- [AS02008MR-HT-WP](https://puiaudio.com/product/speakers-and-receivers/as02008mr-ht-wp) — PUI Audio; Dimensions & Specifications
- [CMC-4015-25T](https://www.sameskydevices.com/product/audio/microphones/electret-condenser-microphones/cmc-4015-25t) — Same Sky; Specifications；datasheet p1
- [TLV320AIC3104](https://www.ti.com/lit/ds/symlink/tlv320aic3104.pdf) — Texas Instruments; Pin functions / Power / Digital interface
- [TPA2010D1](https://www.ti.com/lit/ds/symlink/tpa2010d1.pdf) — Texas Instruments; Application / Gain setting
- [S13V30F5 #4082](https://www.pololu.com/product/4082) — Pololu; Features / Output-current graph
- [LM74502DDFR](https://www.ti.com/lit/ds/symlink/lm74502.pdf) — Texas Instruments; p1 / Pin functions / Typical application
- [CSD18540Q5B](https://www.ti.com/lit/gpn/CSD18540Q5B) — Texas Instruments; Product summary / Package
- [TPS62162DSGR](https://www.ti.com/product/TPS62162/part-details/TPS62162DSGR) — Texas Instruments; Features / Part details
- [451/453 Series Nano2 Fuse](https://www.littelfuse.com/assetdocs/fuse-451-and-453-datasheet?assetguid=533cd5cc-956c-4243-867f-6ab5a62f6ba1) — Littelfuse; p1–3 电气特性/时间电流曲线/外形
- [EEUFR1C471](https://industrial.panasonic.com/kr/products/pt/aluminum-cap-lead/models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) — Panasonic; Model table
- [XA1E-BV302-R](https://www.idec.com/en-us/switches-indicator-lights/switches-pushbuttons/emergency-stop-switches/xa-16mm-estop/xa1e-bv302-r) — IDEC; Key Features / Mechanical Specifications
- [Grove NFC PN532 113020006](https://www.seeedstudio.com/Grove-NFC.html) — Seeed Studio; SKU / Product summary
- [Grove NFC Wiki](https://wiki.seeedstudio.com/Grove_NFC/) — Seeed Studio; Specifications / Hardware overview
- [B6neo Series](https://www.skyrc.com/b6neo-series) — SkyRC; 型号表 / Specification
- [FE-URT-1 Programmer](https://www.feetechrc.com/serial-port-series-steering-gear_50681.html) — FEETECH; FE-URT-1条目
- [SSW-120-02-G-D](https://www.samtec.com/products/ssw-120-02-g-d) — Samtec; 产品标题/Prints
- [IMX219-160 Camera](https://www.waveshare.com/product/risc-v/cameras/imx219-160-camera.htm) — Waveshare; Specifications / Version Options
- [USB TO AUDIO](https://www.waveshare.com/product/usb-to-audio.htm) — Waveshare; Product details

<!-- /atlas-source -->

<!-- atlas-source:2 -->
### 厂家应用支持

按文中定位查阅并核对版本。

- [LM74502 bidirectional current application](https://e2e.ti.com/support/power-management-group/power-management/f/power-management-forum/1503649/lm74502-lm74502-as-high-side-driver-in-back-to-back-connected-com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) — Texas Instruments; TI工程师答复
- [NFC Antenna Dimensions](https://forum.seeedstudio.com/t/nfc-antenna-dimensions/6776) — Seeed Studio 技术支持; 2019-04-26 技术支持回复

<!-- /atlas-source -->

<!-- atlas-source:3 -->
### 项目源代码

按文中定位查阅并核对版本。

- [Microduck software repository](https://github.com/pollen-robotics/microduck) — Pollen Robotics; 本地同源 duck-control/src/imu.rs、bus.rs、deploy/audio/*.dts
- [Microduck RL repository](https://github.com/pollen-robotics/microduck_rl) — Pollen Robotics; 本地 robot_allcollisions.xml 的 sensor/site 与 microduck_constants.py

<!-- /atlas-source -->

---

*AnythingAtlas · 规划学习任何主题的最佳路径*

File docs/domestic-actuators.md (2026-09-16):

# Chinese actuator candidates

There is no zero-change domestic drop-in for the XL330 baseline. The useful distinction is between a **same-size experimental candidate** and a **larger, mature redesign route**.

| Candidate | Public specification | Fit verdict |
|---|---|---|
| DSpower DS-S009C TTL | 23×12×26.5 mm; vendor claims 9 g; 6–7.4 V; magnetic encoder; TTL; up to 11 kgf·cm static stall | highest-priority one-unit bench candidate; mounting, protocol revision and sustained torque require measurement |
| Feetech STS3032 / STS3036 | 17.7–20.6 g; about 4.5 kgf·cm at 6 V; TTL bus; 12-bit feedback | suitable for head/beak experiments or a lighter/slower retrained design |
| Unitree S288 | 20×34×26 mm; 19.5 g; 288.35:1; 12.6 V; 6 Mbps; dual encoder | near-perfect envelope but published torque is below the leg target |
| Unitree J288 | same envelope; 35 g; up to 1.5 N·m; 25.2 V | torque-capable but changes mass, voltage and control stack |
| Feetech STS3215 | 55 g; ~19.5 kgf·cm at 7.4 V | mature low-cost route for a larger ~42 cm Open Duck Mini-style robot |

## DS-S009C sample gate

Before a 15-unit decision, measure one current-revision TTL sample:

- actual mass and dimensions;
- continuous 0.45 N·m load for 10 minutes;
- backlash and return error;
- no-load speed;
- supported baud rates, ID range and broadcast write;
- complete 15-device command + state cycle under 20 ms;
- current and temperature under repeated impact-like trajectories.

The public model name has appeared with different historic torque/protocol descriptions. Record the PCB/firmware revision and archive the exact datasheet received with the sample.

## Software impact

Replacing XL330 changes the packet protocol, mounting zero, actuator response, friction/backlash and supply-current model. A serious replacement therefore includes:

1. a new bus driver;
2. actuator identification;
3. updated MuJoCo/BAM parameters;
4. domain randomization around measured variance;
5. policy retraining and suspended-robot validation.

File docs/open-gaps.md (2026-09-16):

# Rev A open gaps and closure tests

| ID | Gap | Evidence now | Measurement / prototype | Closed when |
|---|---|---|---|---|
| P0-MECH-01 | Simulation mesh lacks fit tolerances | 47 source STL + MJCF kinematic tree | Print M2 and bearing coupon at ±0.00/0.10/0.20/0.30 mm compensation | One compensation table produces repeatable press/slip fits |
| P0-ELEC-01 | `imu_to_dxl` schematic and firmware absent | ID 200; 1 Mbps V2; register 124; 12-byte block recovered from runtime | MCU + LSM6DSV16X prototype answers ping and sync-read alongside one servo | 30-minute 50 Hz read has no stale-run warning and orientation reaches ready |
| P0-PWR-01 | Inferred 2S rail conflicts with XL330 6.0 V rating | Runtime battery constants 6.6/8.2 V; vendor range 3.7–6.0 V | Single-servo stepped-supply characterization with current and temperature log | A documented rail voltage/current limit passes G1 and is reflected in simulation |
| P0-HARNESS-01 | Cable routing absent | Assembly geometry only | One-leg harness mock-up through full joint travel | No pinch/rub and service loop remains at every joint limit |

## Do not freeze before measurements

- Final battery topology and rail voltage.
- Production PCB outline, connectors and copper width.
- Global FDM hole compensation.
- Remaining fourteen actuator purchases.
- Use of the shipped ONNX policies without retraining.

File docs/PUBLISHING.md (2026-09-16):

# 2026-09-16 整理与脱敏发布

## 发布内容

本次以既有公开仓库为基础，整理最新 R9 整机场景、39 件 STL、11 件支撑已启用的试装 3MF、工程评估及分版本历史参考。原工作区不覆盖。当前打印模型处于试装状态，发布整理不构成机械、电气或真机验证。

## 脱敏边界

- 不直接上传整个工作区，不携带本地 Git 配置、凭据、应用/虚拟环境、下载缓存、日志、设备连接文件、打印机 G-code、商家聊天、订单与个人截图。
- 文字中的本机绝对路径转为公开相对入口或历史资料提示；公开上游署名和链接保留。
- Blender 删除带本机路径/设备字段的自定义元数据、嵌入脚本和无用图像；重开后核对对象网格、变换、父子层级和材质分配不变。
- 3MF 解包检查源路径和连接字段，去掉旧缩略图和切片摘要；3D 成员逐字节核对相同，支撑仍启用。去掉缓存后应重新切片。
- 群二维码按维护者要求作为公开邀请入口保留；只清除 JPEG 元数据，不修改二维码像素流。有效期以 README 和原图为准。
- 扫描涵盖发布树文字、结构化 3MF 内容、Blender 可读字符串、图片元数据和文件名；STL 检查固定格式与标题。启发式扫描不代表任意形式的敏感信息都可自动识别。

## 可复核性

运行 `python tools/verify_publication.py modified` 检查文件清单哈希、39 件 STL 格式、3MF 设置与成员、必要文件和 Markdown 链接。

`proof/source-manifest.json` 记录选入资料的工作区相对来源与原始哈希，不包含原文件内容备份。`proof/blender-sanitization.json` 和 `proof/3mf-sanitization.json` 记录本次结构化核验；`models/r9/evidence` 明确标注为历史数字检查。

`ROLLBACK.sh TARGET_README` 仅把指定 README 副本恢复为发布前版本，不删除当前模型、不改动远端。全仓回退应对发布提交执行常规 Git revert 并另行确认推送。本次仅在独立 README 副本上实测恢复。

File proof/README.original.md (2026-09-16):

<!-- changed_branch: publication -->
<!-- changed_field: repository_state -->
<!-- repository_state: public_ready -->

# Microduck Replica Kit 🦆

一个面向 **Microduck 功能兼容复刻** 的、证据可追溯的社区工程包：锁定公开来源，重建参考装配，整理分阶段 BOM，记录尚未闭合的机械与电控问题，并提供可重复运行的导出与验证脚本。

> This is an independent community reconstruction project. It is not affiliated with or endorsed by Pollen Robotics or Hugging Face.

AI-assisted exploded-view concept

> 上图是依据公开照片与仿真几何制作的概念爆炸图，不是原厂制造图。

## 当前状态

| 项目 | 状态 |
|---|---|
| 官方软件与 RL 来源锁定 | ✅ |
| 47 个公开仿真 STL 的装配关系 | ✅ 可重复生成 |
| 整机参考包络 | ✅ 约 144.1 × 141.0 × 264.0 mm |
| 分阶段 BOM 与台架门禁 | ✅ |
| 制造级公差、走线和装配顺序 | 🧪 待实物测量 |
| `imu_to_dxl` 与电源/HAT PCB | 🧪 待自研 |
| 真机行走 | ⏳ 尚未完成 |

Microduck 官方公开的是软件、仿真与训练栈；机械和电子设计文件并未作为开源硬件发布。因此，本仓库区分三类信息：

1. **上游已公开事实**：代码常量、MJCF、仿真网格与官方规格；
2. **可复现推导**：装配变换、尺寸、紧固件与总线分析；
3. **待测假设**：配合公差、电源架构、线束、持续力矩与真机可靠性。

## 仓库内容

```text
.
├── docs/
│   ├── architecture-rev-a.md       # 功能兼容 Rev A 路线
│   ├── domestic-actuators.md       # 国产执行器候选
│   ├── cost-estimate.md             # 首台原型成本区间
│   ├── open-gaps.md                 # 四个 P0 缺口与关闭条件
│   └── images/                      # 概念图
├── hardware/
│   ├── BOM_REV_A.csv               # 分阶段、带采购门禁的 BOM
│   └── test-coupons.md              # M2/轴承/走线打印试片
├── scripts/
│   ├── fetch_upstream.ps1           # 按提交哈希抓取上游
│   └── export_reference_assembly.py # 从 MJCF 重建装配 STL
├── tools/validate_repo.py           # 静态发布验证
├── source-lock.json                 # 上游 URL、分支和提交哈希
├── NOTICE.md                        # 来源与许可证边界
└── LICENSE                          # 本仓原创代码：Apache-2.0
```

## 快速开始（Windows PowerShell）

```powershell
git clone https://github.com/qianen6/microduck-replica-kit.git
cd microduck-replica-kit

# 1. 拉取锁定版本的上游源码
powershell -ExecutionPolicy Bypass -File scripts/fetch_upstream.ps1

# 2. 创建几何工具环境
python -m venv .venv
.\.venv\Scripts\python.exe -m pip install -r requirements-geometry.txt

# 3. 从官方 MJCF 生成参考装配
.\.venv\Scripts\python.exe scripts/export_reference_assembly.py `
  upstream/microduck_rl generated/reference-assembly

# 4. 验证仓库
python tools/validate_repo.py --mode modified --readme README.md
```

参考导出在锁定来源上应得到：15 个刚体文件、整机 796,792 个三角面、包络约 `144.1 × 141.0 × 264.0 mm`。

## 推荐实物顺序

1. 单舵机 50 Hz 总线、电流和温升台架；
2. M2 孔、热熔螺母与两种轴承试片；
3. 一条五自由度腿和真实线束；
4. 15 舵机 + IMU 的完整总线；
5. 吊架上的 home / sit / stand / fall-to-limp；
6. 最后运行或重训行走策略。

详见 [Rev A 架构](docs/architecture-rev-a.md) 与 [P0 缺口](docs/open-gaps.md)。

## 上游

- [pollen-robotics/microduck](https://github.com/pollen-robotics/microduck) — 机器人运行时与控制栈
- [pollen-robotics/microduck_rl](https://github.com/pollen-robotics/microduck_rl) — MJCF、仿真网格和 RL 训练
- [fanhao375/microduck-replica](https://github.com/fanhao375/microduck-replica) — 装配、电控和紧固件逆向研究

具体提交见 [`source-lock.json`](source-lock.json)。

## 许可证

- 本仓原创代码、脚本和文字：Apache License 2.0；
- 从上游 Microduck 3D 模型生成的几何衍生物：CC BY-NC-SA 4.0；
- 概念爆炸图：CC BY-NC-SA 4.0；
- 上游项目仍由各自许可证约束。

完整来源和署名见 [`NOTICE.md`](NOTICE.md)。

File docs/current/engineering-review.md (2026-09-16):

# R9：按证据取舍的工程评估与模型修订

## 结论与交付状态

已完成数字工程评估，并形成 **R9 工程试装版**。本次修改 11 个现有网格、新增 2 个打印参考件，共 13 个几何对象；原模型保留，当前 Blender 打开修订副本。

这不是整机可靠性认证。模型仍保留 `manufacturing_release=false`、`physical_fit_verified=false`、`electrical_release=false`。相机板厚、紧固件、轴向叠层、真实负载/电流/温升和完整运动范围仍需实测。

## 1. 哪些设计证据更强

| 项目 | 评估 | 本次取舍 |
|---|---|---|
| 已购相机、电池的规格对应 | 我们这一侧有用户提供的实物商品尺寸图；对方的 IMX219/NP-F550 并非同一采购方案。这里只说明匹配证据更强，不说明元件质量更高。 | 保留 OV5647、6.4V 电池和当前主控布局；按新图修正孔位与镜头偏置。 |
| 飞特舵盘接口 | 对方公布了 HD-1910 改件并报告整机装配，作为试装参考强于仅凭外形替换。 | 在小腿、yaw2roll、头部 yaw/roll 采用与我们原件相交得到的净空切削部分，不把未经核验的新增凸台整体搬入。 |
| 轴承座与装配基准 | 对齐到我们安装面后，直接加厚候选产生新的轴承相交；对方自身总装未在本次导入，所以这不等于对方整机存在同样问题。 | 保留我们的原安装面。躯干底座、两片 bearing-roll 在有空间处局部加厚；左右上腿加固板加厚方案被否决，保留原几何并标注轴向叠层待重设计。 |
| 文件格式与网格 | STEP/SolidWorks 本身不是制造合格证。对方两上腿、底座 STEP 经 OpenCascade 检查有效，但转换 STL 有接缝。我们面板也存在零面积碎片。 | 不把转换缝隙判成原 CAD 损坏；修复我们面板的退化网格，13 个修订网格全部闭合且单连通。 |
| OpenRB 通讯路径 | 原厂 `usb_to_dynamixel` 代码逐字节转发串口数据，因此仅凭 DYNAMIXEL 名称就否定该板并不充分。其官方标注舵机端口 3A；HD-1910 的主机协议、接插件和实际电气连接仍须验证。 | 保留为有条件候选，不把它标成已完成飞特适配。对方 URT-2 的配 ID 操作证据不等于整机电控闭环。 |
| 电池供电 | 用户图只标注输出 0-3A，没有给出整机动作下的峰值、压降或保护阈值。 | 撤销把 3A 直接写成已知连续输出能力的表述，改为广告输出范围；不标记 15 舵机动态供电已验证。 |
| 强度、寿命、跌倒冲击 | 双方都缺少本次可核验的材料、打印层向、负载谱和寿命结果。 | 不给出额定强度或寿命保证；“更厚”只作为候选结构，不作为充分可靠性证据。 |

对方机械试装依据：[飞特 v2.0 发布说明](https://github.com/fanhao375/microduck-replica-cad/releases/tag/v2.0)、[构建日志](https://github.com/fanhao375/microduck-replica/blob/master/%E6%9E%84%E5%BB%BA%E6%97%A5%E5%BF%97.md)。

OpenRB 依据：[ROBOTIS 官方手册](https://emanual.robotis.com/docs/en/parts/controller/openrb-150/)、[原厂串口桥接示例](https://github.com/ROBOTIS-GIT/OpenRB-150/blob/master/libraries/OpenRB-150/examples/usb_to_dynamixel/usb_to_dynamixel.ino)。桥接源码已保存为 `[LOCAL_PATH]`，未刷写任何设备。

## 2. 本次实际完成的修改

### 相机：修正二维尺寸和实际装配通道

- PCB 外形 25×24mm，四孔直径 2mm、孔距 21×12.5mm；顶排孔距板顶 2mm，左右距边 2mm。
- 镜头中心距板底由原先居中假设修正为 **10.25mm**，光轴方向及在头部的 Y/Z 基准保留。
- 板厚 1.2mm 仍是模型假设；镜头整体深度沿用用户给出的 9mm 包络，内部镜片和排线连接器未冒充精细实测模型。
- 新增四孔相机承架，打印孔径 2.4mm，背面名义元件空间 3mm。
- 视觉复核发现下排孔的正面工具通道需要避让，已补 **直径 4.6mm 的螺钉头/工具通道**；四处支撑环及通孔均进行几何检查。
- 沿用旧镜头座与面板的名义连接几何，剔除与新载板无连接的旧 M12 套筒残片。固定座须与真实板厚、焊点、螺钉长度共同试装。

### 电池：保留约束方式，增加可拆后盖

- 保留 19×37×66mm 电池及原托架/绑带约束，不靠新盖板夹紧电芯。
- 新增 2mm 后盖，名义电池后方空隙 **4.5mm**；采用上下安装耳而非最初会侵占髋部空间的侧耳。
- 四处 2.4mm 通孔；安装耳位于电池包上下端之外，检查未侵入名义电池体积。
- 顶部开口 16×8mm，另有可选扎带孔；真实导线直径、弯曲半径和充电插头操作空间仍需试装。接触导线的打印边缘需按实际护套/收口处理。
- 后盖是可拆卸保护件，不是密封壳。紧固件长度、螺母/垫片和充电器与电池化学体系的匹配另行核对。

### 机械件：局部改进，不破坏原安装基准

- 躯干底座及左右 bearing-roll 连接片保留原有轴承座、安装面和孔位，仅在相邻名义包络之外增加材料。
- 新增材料的 0.15mm 避让是数字筛选值，尚未覆盖厂家公差与实际 FDM 误差的完整叠加。
- 左右小腿、左右 yaw2roll 和头部 yaw/roll 共五件，采用 FT 版本的净空切削部分；不增加原先自由空间中的材料。
- 左右上腿加固板继续保持原几何，标注待轴向叠层重设计；左右上腿主体也没有强行移植未经闭合转换及实物叠层核验的凸台。
- 去除面部零件零面积碎片、修复微小接缝；几何简化容差 0.001mm，未把原面板大幅重塑。

## 3. 检查结果与其适用范围

| 检查 | 结果 | 解释 |
|---|---|---|
| 修订几何 | 13/13 闭合、单连通 | 包括 11 个原件和 2 个新增件；不是整机制造放行。 |
| 相机孔位/支撑面/工具通道 | 通过 | 基于用户二维图；实际板厚及紧固件未实测。 |
| 后盖固定孔周边材料及电池包相交 | 通过；包络相交为 0 | 只针对名义尺寸。 |
| 中立姿态闭合网格相交回归 | 新增大于 0.1mm³ 的相交项为 0 | 原先的名义相交尚存在，需区分预期配合、代理几何误差和真实干涉。 |
| OpenRB 与头部 yaw/roll、相机承架表面检查 | 均为 0 对相交三角面 | 表面检查不证明实体包含或所有电缆净空。 |
| 运动抽样 | 235 个姿态；仍有 82 条新增材料相交记录 | 含原先已相交的极限姿态与名义配合；不宣称完整运动范围无干涉。 |
| 新后盖引出的新对象对 | 9 条，均在原电池/托架/机壳已阻挡的样本中 | 仅在此抽样集合内，没有新增“原机壳可通行样本”的阻挡；这不是连续扫掠证明。 |
| 舵机、原件位姿、层级和已有材质 | 已回归核对 | 不移动关节基准来掩盖问题。 |
| 回滚 | 独立副本恢复到修改前，哈希一致 | 原来源文件未覆盖。 |

运动检查使用原 MuJoCo 运动学链的中立、单关节端点/半行程、密集髋 yaw 采样和确定性随机姿态。没有进行动力学仿真、策略训练或实机通电。

厂家 STEP 用于额外名义包络检查时包含全部 14 个实体；其中 6 个小实体采用保守凸包，8 个保留离散曲面。故重叠量是辅助筛查，不直接等同真实干涉。原厂二维尺寸图也用于复核测量边界：（本地供应商参考图，未随公开包分发）

## 4. 仍未解决、也没有伪装成已解决的事项

1. **上腿轴向叠层与舵盘实物配合**：需量安装面、舵盘端面、轴承座和螺钉长度；本次保留相关原件并加待复核标记。
2. **完整运动范围**：当前样本包含原机壳已自干涉的姿态，应先确定真实机械限位及可用动作范围，再做连续扫掠与负载验证。
3. **15 舵机供电与通讯**：电池广告 0-3A、OpenRB 端口 3A 不是整机动态余量证明；需要台架记录峰值电流、总线最低电压、温升和保护动作。
4. **实际制造误差**：相机板厚、紧固件、材料牌号、打印方向/层间强度和收缩量均未在本次测得。

建议先打印相机承架和后盖做低成本试装，再做单关节台架。原模型与完整回滚副本均保留。

## 交付

- R9 工程试装模型（历史本地资料）
- 逐对象差异及检查数据（历史本地资料）
- 验证命令和实际输出（历史本地资料）
- 回滚脚本（历史本地资料）
- 相机承架试装 STL（历史本地资料）
- 电池后盖试装 STL（历史本地资料）

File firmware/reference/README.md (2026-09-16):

# 原厂串口桥接参考

ROBOTIS OpenRB-150 原厂 usb_to_dynamixel 示例，保留 Apache-2.0 版权头。来源：https://github.com/ROBOTIS-GIT/OpenRB-150/blob/master/libraries/OpenRB-150/examples/usb_to_dynamixel/usb_to_dynamixel.ino

仅作为协议路径研究参考；不是经过验证的 HD-1910 驱动，未刷写设备。

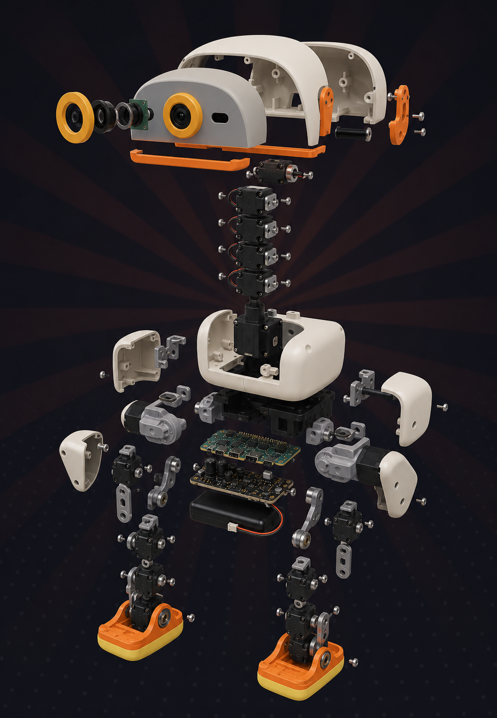
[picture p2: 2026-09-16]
docs/images/exploded-view-concept.png

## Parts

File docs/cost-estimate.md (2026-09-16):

# First-prototype cost estimate

Indicative DIY material budget as of the source snapshot date; engineering labor is excluded.

| Category | Range (CNY) |
|---|---:|
| 15 compact smart actuators | 2,800–4,500 |
| Radxa-class compute | 250–450 |
| IMU, MCU, ToF and camera | 400–800 |
| custom PCB, bus and power prototypes | 500–1,500 |
| battery and charger | 150–350 |
| printing | 200–1,200 |
| fasteners, bearings and harness | 300–700 |
| debug adapter | 100–300 |
| rework and spares | 800–1,500 |
| **Total** | **5,500–11,300** |

A practical planning number for the first runnable prototype is approximately CNY 10,000. Outsourced CAD, PCB design, assembly and printing can move the first article above CNY 15,000.

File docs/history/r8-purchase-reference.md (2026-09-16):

> 历史参考：对应旧版硬件/几何；不得视为 R9 当前 BOM、接线或打印放行。

## 2026-09-13：轴承与一次备料总表

本次重新读取正在打开的 Blender 场景，38 个打印件、15 个舵机和14个轴承，共67个对象的网格/变换与已审磁盘文件一致。轴承逐个测量内径、外径和宽度，不是只看文件名。原模型与未保存状态保留。

### A. 轴承：型号、尺寸和模型数量已直接核实

尺寸顺序统一为 **内径 × 外径 × 厚度**，单位 mm。选无凸缘、普通内圈宽度的径向深沟球轴承。

| 型号/订货描述 | 尺寸 mm | 模型实需 | 建议购买 |
|---|---|---:|---:|
| MR2216-ZZ，金属防尘盖 | 16×22×4 | 11 | 12 |
| 6700 开式，或明确标注 W3 的 3 mm 厚版本 | 10×15×3 | 3 | 4 |

大轴承分布：躯干两处、左右腿各三处、头颈三处，共11个。小轴承分布：左右脚踝各1个，头/喙侧1个，共3个。

MR2216-ZZ 的尺寸对应 [MBA 目录第117页](https://files.minibearings.au/pdf/catalogues/Bearings%20-%20Radial%20-%20Master%20List.pdf#page=117)。[Runstar 6700开式](https://www.runstarbearing.com/product/thin-section-ball-bearings-6700/) 为10×15×3；[ISK 6700ZZ](https://iskbearing.com/product-details/6700zz) 为10×15×4。订货以三个尺寸为准，标4 mm厚的6700ZZ/2RS不作为当前3 mm位置的直接替换。

### B. 螺丝：一次备料建议，与轴承的直接确认数量分开

**以下是备料数，不是全机实装净用量。** 为形成可执行的长度组合，对108个舵机候选固定位置临时采用“接收端兼容M2、啮合1.5–3.0 mm、尽量接近2.0 mm”的计算场景，再加入22个非舵机名义选型位置。模型未标注的HD-1910牙型和允许深度仍未被确认；若为塑料专用自攻牙，应使用匹配牙型的配套螺丝，而不是把机牙螺丝强行代用。

| 规格 | 场景计算分配，非实需 | 建议购买备料数 |
|---|---:|---:|
| M2×3 | 18 | 30 |
| M2×4 | 32 | 40 |
| M2×5 | 54 | 60 |
| M2×6 | 15 | 30 |
| M2×8 | 备用，未指定安装位 | 10 |
| M2.5×5 | 4 | 10 |
| M2.5×8 | 7 | 15 |

上述机牙备料选择平底承压的内六角圆柱头，常规304不锈钢即可；不要统一购买锥形沉头。对板卡螺丝还应核对实际螺帽外径与周围元件空间。M2×8列为备用，不声称模型必用10颗。

轴心原配螺丝和相机/镜头固定不被擅自计入场景130个安装位；源模型保留的偏孔与螺柱复查项仍见下文，采购备料不等于这些问题已经修复。

### C. 小配件

| 配件 | 模型明确使用量 | 建议购买 |
|---|---:|---:|
| M2薄平垫，参考内径2.2、外径4.0、厚0.3 mm | OpenRB 4片 | 10片 |
| M2.5薄平垫，参考内径2.7、外径4.5、厚0.3 mm | Pi 4片 | 10片 |
| M2普通螺母 | 通孔试配备用，不按必装件计算 | 10个 |
| M2.5普通螺母 | 通孔试配备用，不按必装件计算 | 10个 |

模型没有把所有1.6 mm导孔设计为热熔螺母孔；本表不建议直接往这些小孔压入热熔螺母。

### D. 逐个轴承对应

| 模型对象 | 型号对应 | 内径×外径×厚度 mm |
|---|---|---|
| `PART_01_trunk_base_seeed_bearing__configuration__22x16x4` | MR2216-ZZ | 16×22×4 |
| `PART_08_trunk_base_seeed_bearing__configuration__22x16x4` | MR2216-ZZ | 16×22×4 |
| `PART_10_yaw2roll_seeed_bearing__configuration__22x16x4` | MR2216-ZZ | 16×22×4 |
| `PART_12_hip_l_seeed_bearing__configuration__22x16x4` | MR2216-ZZ | 16×22×4 |
| `PART_16_upper_leg_left_seeed_bearing__configuration__22x16x4` | MR2216-ZZ | 16×22×4 |
| `PART_20_ankle_left_seeed_bearing__configuration_default` | 6700 OPEN / W3 (3 mm width) | 10×15×3 |
| `PART_25_neck_pitch_seeed_bearing__configuration__22x16x4` | MR2216-ZZ | 16×22×4 |
| `PART_27_yaw_roll_motion_seeed_bearing__configuration__22x16x4` | MR2216-ZZ | 16×22×4 |
| `PART_28_yaw_roll_motion_seeed_bearing__configuration__22x16x4` | MR2216-ZZ | 16×22×4 |
| `PART_34_jaw_soft_seeed_bearing__configuration_default` | 6700 OPEN / W3 (3 mm width) | 10×15×3 |
| `PART_45_bearing_roll_seeed_bearing__configuration__22x16x4` | MR2216-ZZ | 16×22×4 |
| `PART_47_hip_l_2_seeed_bearing__configuration__22x16x4` | MR2216-ZZ | 16×22×4 |
| `PART_48_upper_leg_right_seeed_bearing__configuration__22x16x4` | MR2216-ZZ | 16×22×4 |
| `PART_54_ankle_right_seeed_bearing__configuration_default` | 6700 OPEN / W3 (3 mm width) | 10×15×3 |

本次测量及备料假设数据（历史本地资料）

---

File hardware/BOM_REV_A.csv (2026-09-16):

id | category | item | quantity | total_target | phase | confidence | procurement_gate | evidence_or_note
A01 | actuator | Dynamixel XL330-M288-T | 1 | 15 | G1 | high | buy_one_only | 18 g; 288.4:1; V2 TTL; remaining 14 after G1/G2
A02 | actuator | Dynamixel XL330-M288-T | 14 | 15 | G3 | high | after_G1_G2 | bulk purchase gated by supply and fit tests
C01 | compute | Radxa Zero 3W 1GB RAM 32GB eMMC target | 1 | 1 | G4 | high | after_G1 | official runtime targets RK3566/Radxa Zero 3W
S01 | sensor | LSM6DSV16X breakout for protocol prototype | 1 | 1 | G1 | high | buy_one | SFLP quaternion source for ID 200
S02 | sensor | VL53L8CX breakout | 1 | 1 | G5 | medium | after_G4 | 8x8 ToF at I2C address 0x29
S03 | sensor | IMX219 camera module and matching CSI cable | 1 | 1 | G5 | medium | after_G4 | camera path does not gate locomotion
E01 | electronics | MCU development board with SPI and 1Mbps UART | 1 | 1 | G1 | medium | buy_one | prototype `imu_to_dxl`; final MCU frozen after timing test
E02 | electronics | 3.3V TTL half-duplex interface prototype | 1 | 1 | G1 | high | buy_one | Dynamixel V2 single-wire bus
E03 | electronics | USB-to-Dynamixel/TTL debug adapter | 1 | 1 | G1 | high | buy_one | bench commissioning and ID assignment
P01 | power | Current-limited adjustable bench supply >=6V | 1 | 1 | G1 | high | use_existing_or_buy | characterize one servo before battery design
P02 | power | High-current regulated servo rail | 1 | 1 | G3 | low | after_G1 | voltage/current rating is deliberately TBD
P03 | power | 5V UBEC/DC-DC for SBC | 1 | 1 | G4 | medium | after_G1 | separate compute rail
P04 | power | NP-F550 battery and external charger | 1 | 1 | G5 | medium | after_G4 | battery topology frozen after rail characterization
P05 | power | Fuse switch and emergency power disconnect | 1 | 1 | G3 | high | after_G1 | bench and assembled robot power isolation
W01 | wiring | JST EHR-03 housings + SEH-001T-P0.6 terminals + 21AWG wire | TBD | TBD | G3 | high | after_one_leg_route | XL330 connector family from vendor manual
M01 | mechanical | OD22 ID16 W4 bearing | TBD | TBD | G2 | medium | after_coupon | size recovered from mesh
M02 | mechanical | OD15 ID10 W3 bearing | 3 | 3 | G2 | medium | after_coupon | quantity recovered from assembly analysis
F01 | fastener | M2x4 socket-head screws | 60 | 60 | G3 | medium | after_coupon | length/count reconstructed from mesh
F02 | fastener | M2x6 socket-head screws | 80 | 80 | G3 | medium | after_coupon | length/count reconstructed from mesh
F03 | fastener | M2x8 socket-head screws | 40 | 40 | G3 | medium | after_coupon | length/count reconstructed from mesh
F04 | fastener | M2x12 socket-head screws | 15 | 15 | G3 | medium | after_coupon | length/count reconstructed from mesh
F05 | fastener | M2 nuts | 50 | 50 | G3 | medium | after_coupon | trial quantity
F06 | fastener | M2 heat-set inserts | 60 | 60 | G3 | medium | after_coupon | preferred over directly tapping printed plastic
F07 | fastener | M2.5x6 screws | 20 | 20 | G3 | low | after_coupon | small number of 2.7/2.8mm features

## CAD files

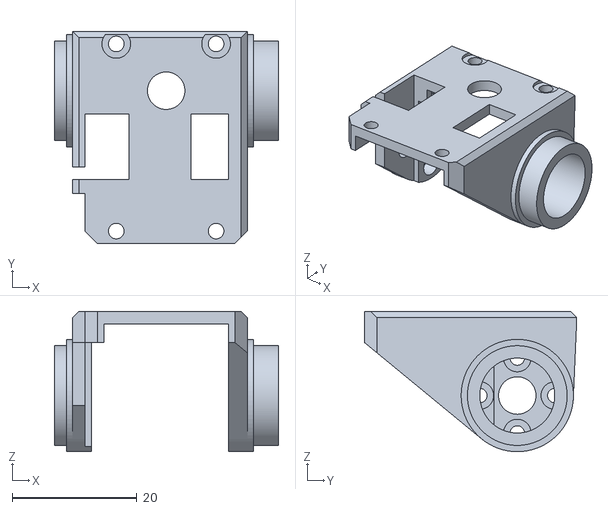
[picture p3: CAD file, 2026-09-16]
models/r9/stl/PART_26_yaw_roll_motion_yaw_roll_motion.stl
35.9 x 34.0 x 22.5

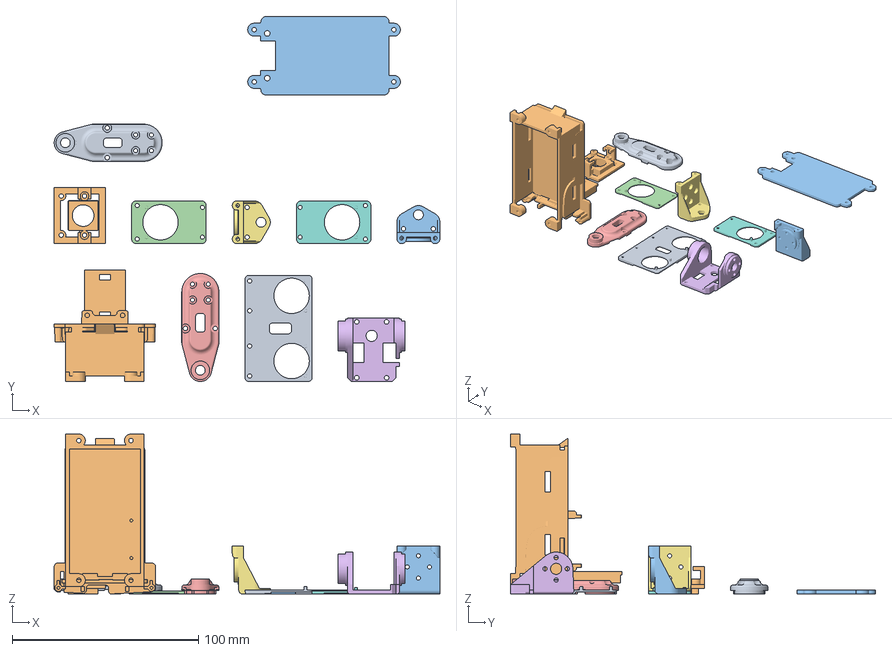
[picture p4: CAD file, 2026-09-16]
printing/r9/R9_11_parts_support.3mf
207.1 x 196.0 x 85.9 mm
PART_04_trunk_base_trunk_base
PART_05_trunk_base_power_support
PART_09_yaw2roll_yaw2roll
PART_11_yaw2roll_bearing_roll
PART_17_leg_leg
PART_26_yaw_roll_motion_yaw_roll_motion
PART_43_bearing_roll_yaw2roll
PART_44_bearing_roll_bearing_roll
PART_51_leg_2_leg
R9_OV5647_CAMERA_CARRIER
R9_BATTERY_REAR_COVER

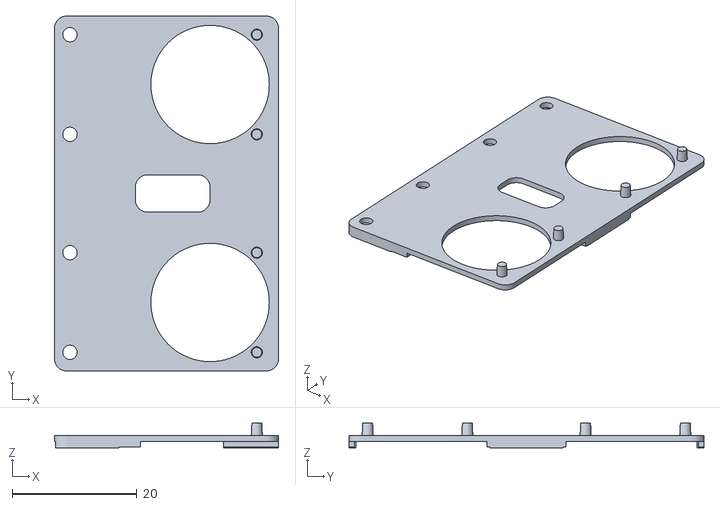
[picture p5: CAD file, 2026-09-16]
models/r9/stl/PART_04_trunk_base_trunk_base.stl
36.0 x 57.0 x 4.00

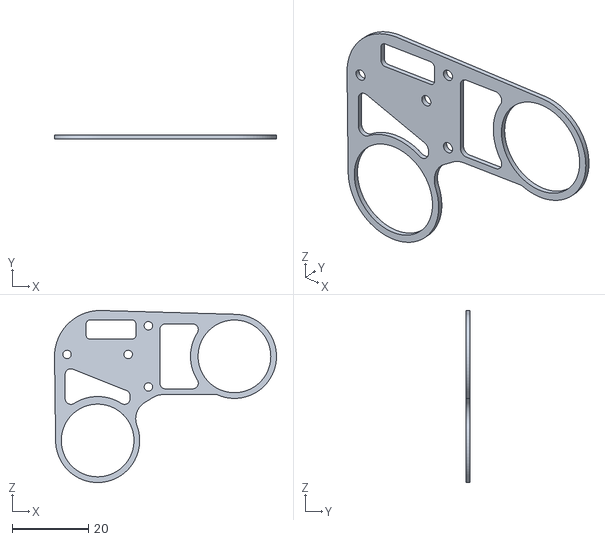
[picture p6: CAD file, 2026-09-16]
models/r9/stl/PART_49_upper_leg_right_upper_leg_rigidity_plate.stl
58.1 x 1.00 x 45.0

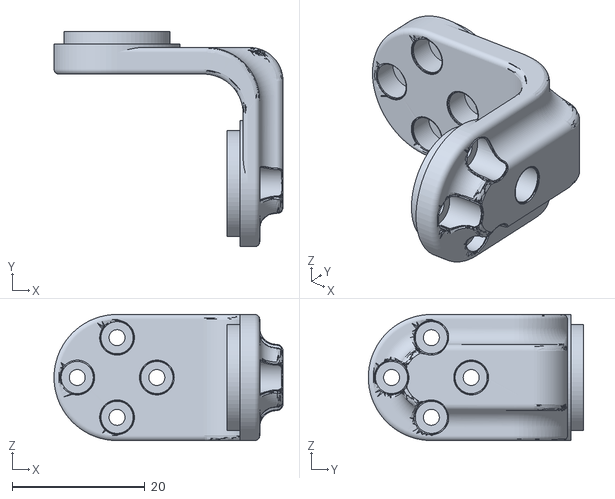
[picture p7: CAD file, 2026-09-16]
models/r9/stl/PART_13_hip_l_hip_l.stl
34.5 x 32.5 x 19.0

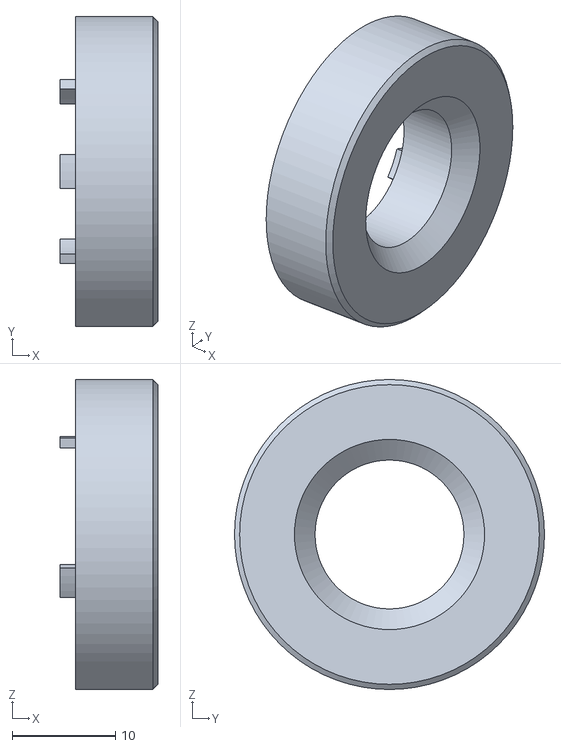
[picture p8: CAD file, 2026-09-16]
models/r9/stl/PART_37_jaw_soft_noenoeil.stl
9.50 x 30.0 x 30.0

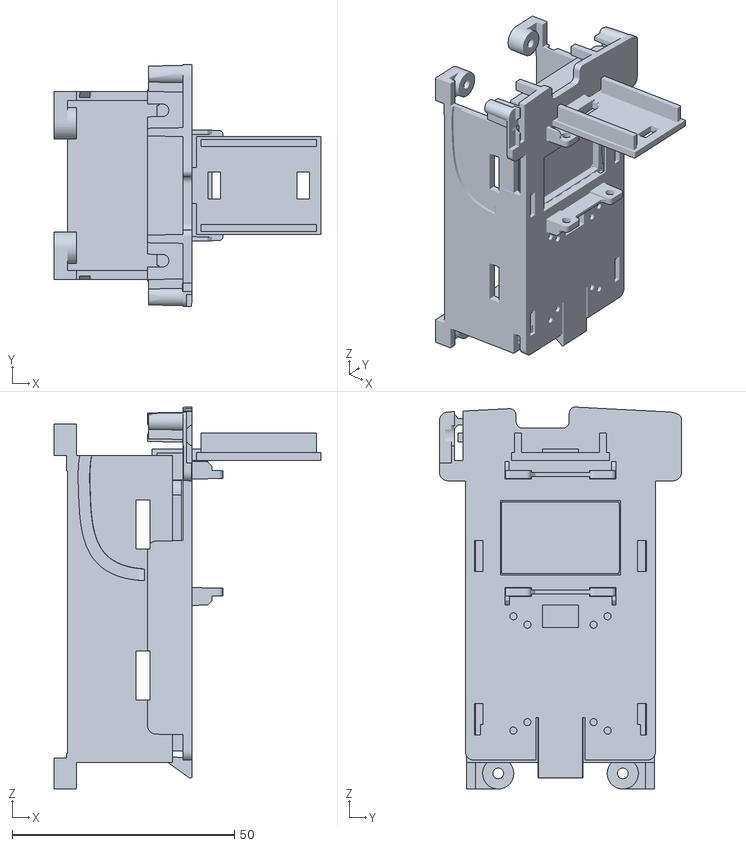
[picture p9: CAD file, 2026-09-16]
models/r9/stl/PART_05_trunk_base_power_support.stl
60.0 x 54.5 x 85.9

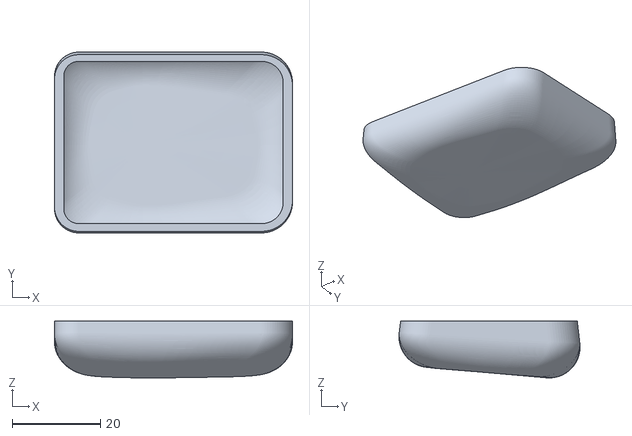
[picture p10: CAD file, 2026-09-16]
models/r9/stl/PART_53_ankle_right_sole_right.stl
54.0 x 41.1 x 12.9

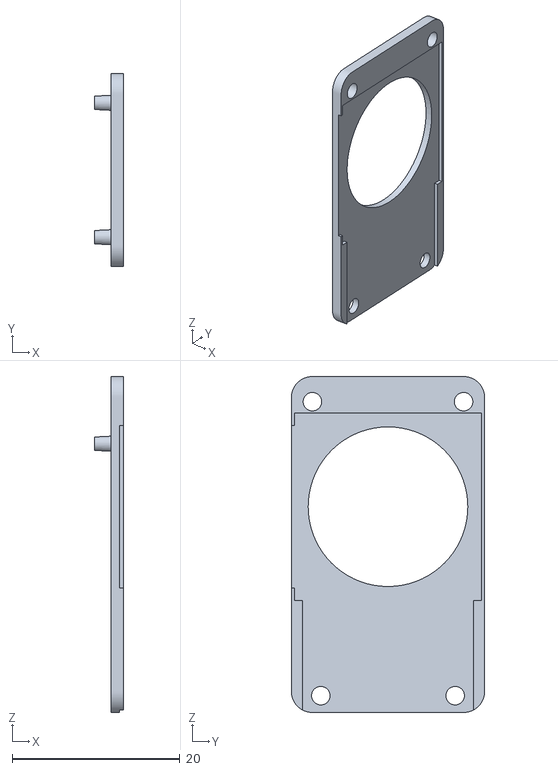
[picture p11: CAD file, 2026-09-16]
models/r9/stl/PART_44_bearing_roll_bearing_roll.stl
3.50 x 23.0 x 40.0

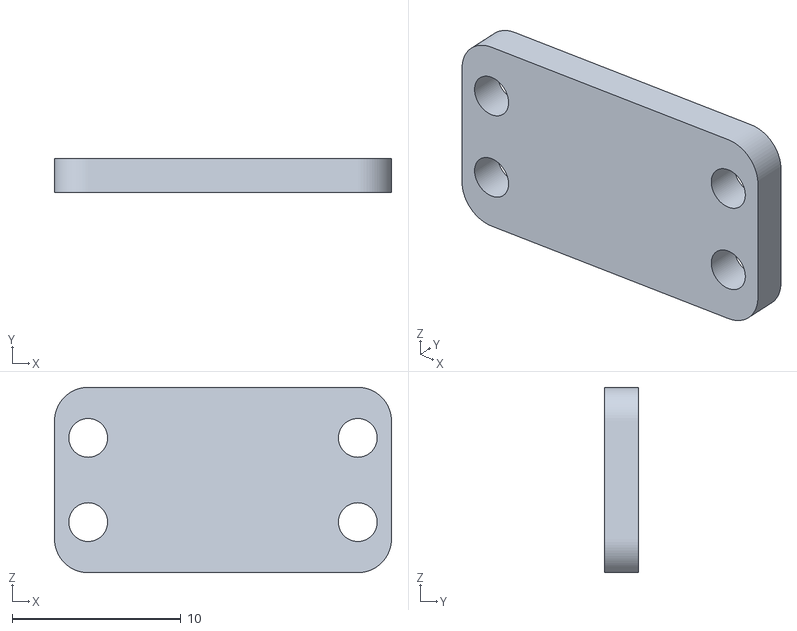
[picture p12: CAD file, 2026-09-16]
models/r9/stl/PART_22_neck_neck.stl
20.0 x 2.00 x 11.0

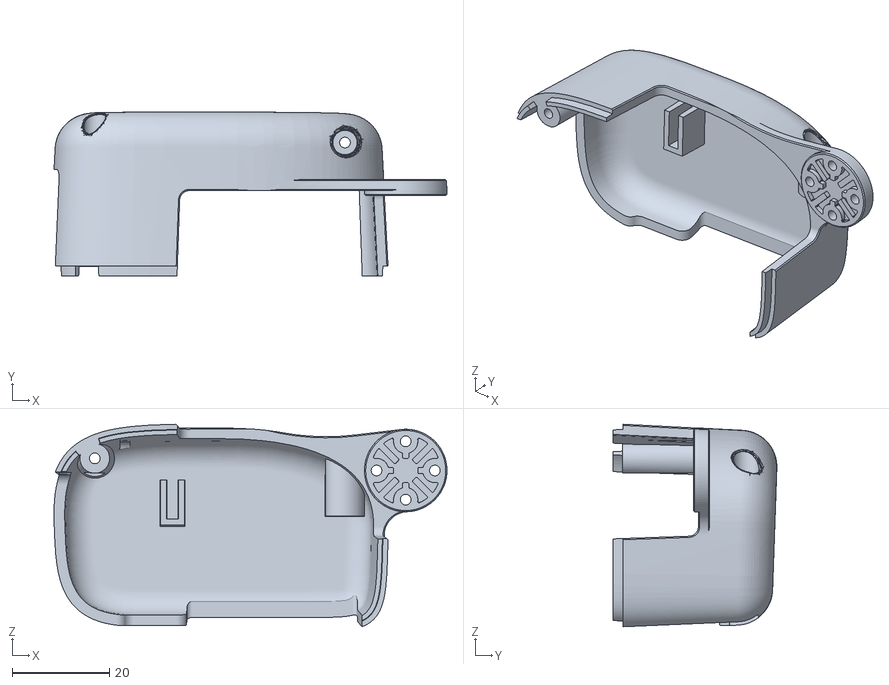
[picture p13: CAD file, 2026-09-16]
models/r9/stl/PART_07_trunk_base_left_shell.stl
80.9 x 33.7 x 41.7

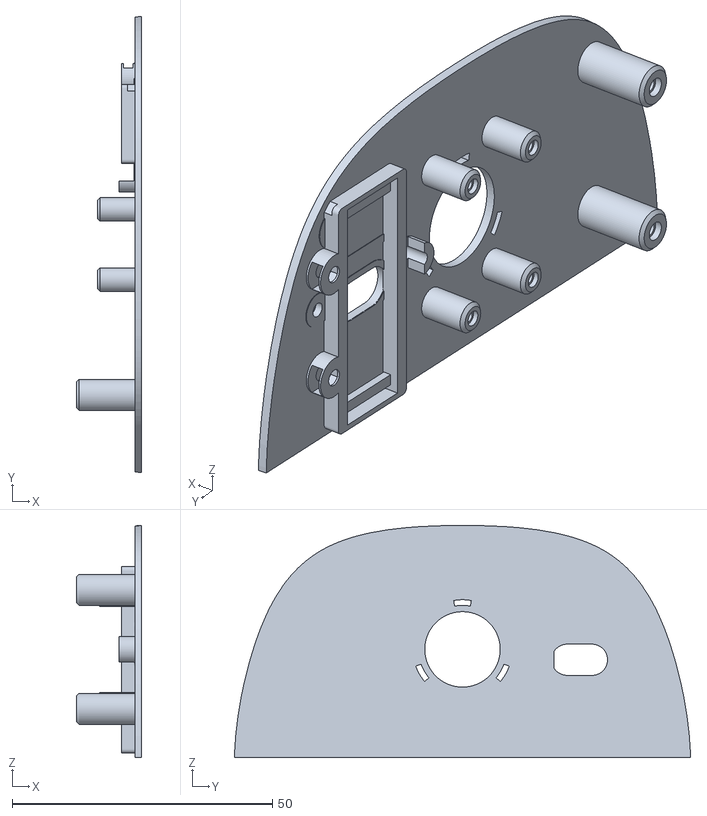
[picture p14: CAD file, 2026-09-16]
models/r9/stl/PART_30_jaw_soft_face_part.stl
12.5 x 87.7 x 44.6

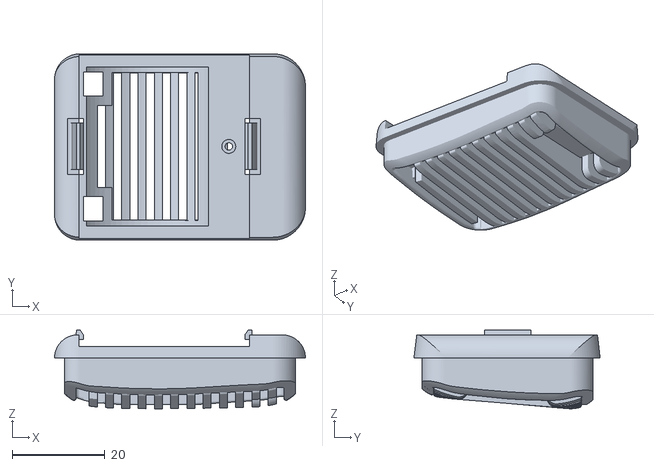
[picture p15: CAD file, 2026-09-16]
models/r9/stl/PART_55_ankle_right_foot_right.stl
54.0 x 40.1 x 16.9

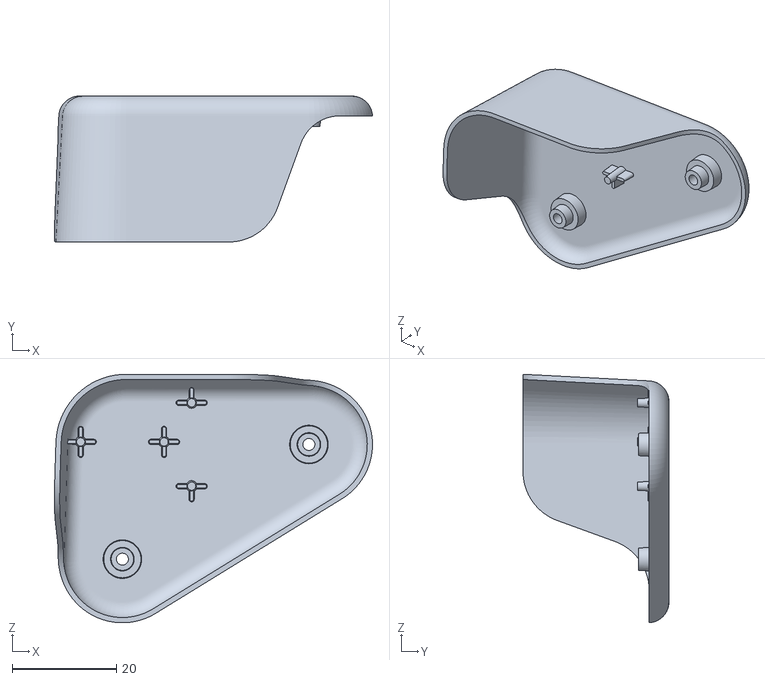
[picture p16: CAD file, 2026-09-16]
models/r9/stl/PART_14_upper_leg_left_upper_leg_left.stl
61.0 x 28.0 x 47.7

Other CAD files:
models/r9/stl/PART_17_leg_leg.stl
models/r9/stl/PART_19_ankle_left_foot_left.stl
models/r9/stl/PART_09_yaw2roll_yaw2roll.stl
models/r9/stl/PART_02_trunk_base_right_shell.stl
models/r9/stl/PART_03_trunk_base_banana_pcb_locker.stl
models/r9/stl/PART_11_yaw2roll_bearing_roll.stl
models/r9/stl/PART_15_upper_leg_left_upper_leg_rigidity_plate.stl
models/r9/stl/PART_18_ankle_left_sole_left.stl
models/r9/stl/PART_21_ankle_left_ankle_left.stl
models/r9/stl/PART_23_neck_neck.stl
models/r9/stl/PART_24_neck_pitch_neck_pitch.stl
models/r9/stl/PART_31_jaw_soft_jaw_soft.stl
models/r9/stl/PART_32_jaw_soft_motor_support.stl
models/r9/stl/PART_33_jaw_soft_top_head_shell.stl
models/r9/stl/PART_36_jaw_soft_soft_mouth_top.stl
models/r9/stl/PART_38_jaw_soft_jaw.stl
models/r9/stl/PART_39_jaw_soft_bottom_head_shell.stl
models/r9/stl/PART_43_bearing_roll_yaw2roll.stl
models/r9/stl/PART_46_hip_l_2_hip_l.stl
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

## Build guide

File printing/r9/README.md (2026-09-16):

# R9 打印文件说明

## 两类文件不要混淆

- `models/r9/stl`：从当前 R9 场景导出的 **39 件**打印对象，毫米单位、零件局部坐标。轴承、舵机和板卡不作为打印件导出。尚需按实际打印机确定方向、材料、支撑和公差。
- 本目录 `R9_11_parts_support.3mf`：既有 **11 件**工程试装排版子集，两盘，不是完整整机套件。第一盘 10 件黑色 PLA（耗材 4），第二盘 1 件浅紫色电池后盖（耗材 3）。P1S / 0.4 mm / 纹理 PEI，100% 尺寸。

## 支撑与脱敏

3MF 保留 `enable_support=1`、`tree(auto)` 和 30° 阈值，保留 3D 网格、变换、材料及盘分配。发布时移除了缩略图/旧切片摘要，并排查连接字段和源路径。Bambu Studio 打开后应重新生成预览、检查朝向、选择本机耗材后重新切片。未包含设备凭据、机器 G-code，也未发送打印任务。

2026-09-14 的本地切片记录有 899 个支撑特征段及 330 个支撑界面段；这是历史单盘记录，不是此公开包的全机时长/重量承诺。本次未重跑切片。

先做相机承架和电池盖试装，核对板厚、焊点、螺钉头及工具通道，再扩展结构件。完整运动范围、电气与实物强度尚未通过验证。

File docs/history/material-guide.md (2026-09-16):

> 历史参考：对应旧版硬件/几何；不得视为 R9 当前 BOM、接线或打印放行。

# HD-1910 嘉立创3D打印材料选择清单

## 结论

材料判断可以由本清单完成，用户不需要逐个零件重新判断。嘉立创网页仍要求每个上传模型填写材料与工艺；用户可以按照本清单手动选择，也可以让Codex在已经登录的浏览器中代为填写。订单提交、工程审核后的最终确认和付款应当在核对数量与报价后执行。

## 推荐的首轮下单顺序

1. 用户先上传 `[LOCAL_PATH]`，并选择“PLA-P塑料／FDM熔融沉积”，数量选择1件。该件只用于验证孔位、舵盘、插头、线束和螺钉空间。
2. 用户在首件通过后上传一个关节或一条左腿所需的结构件，并选择“PA12尼龙／MJF多射流熔融”。
3. 用户把左鞋底选择为“TPU／FDM熔融沉积”，并先验证硬度、摩擦和尺寸。
4. 用户在单关节与单腿通过后再上传剩余零件，并按照下面的三组材料完成批量选择。

## 第一组：PA12尼龙／MJF多射流熔融

以下24个结构文件应当选择PA12尼龙：

- `PART_03_trunk_base_banana_pcb_locker.stl`
- `PART_04_trunk_base_trunk_base.stl`
- `PART_05_trunk_base_power_support.stl`
- `PART_09_yaw2roll_yaw2roll.stl`
- `PART_11_yaw2roll_bearing_roll.stl`
- `PART_13_hip_l_hip_l.stl`
- `PART_14_upper_leg_left_upper_leg_left.stl`
- `PART_15_upper_leg_left_rigidity_plate.stl`
- `PART_17_leg_leg.stl`
- `PART_19_ankle_left_foot_left.stl`
- `PART_21_ankle_left_ankle_left.stl`
- `PART_22_neck_neck.stl`
- `PART_23_neck_neck.stl`
- `PART_24_neck_pitch_neck_pitch.stl`
- `PART_26_yaw_roll_motion_yaw_roll_motion.stl`
- `PART_32_jaw_soft_motor_support.stl`
- `PART_43_bearing_roll_yaw2roll.stl`
- `PART_44_bearing_roll_bearing_roll.stl`
- `PART_46_hip_l_2_hip_l.stl`
- `PART_49_upper_leg_right_rigidity_plate.stl`
- `PART_50_upper_leg_right_upper_leg_right.stl`
- `PART_51_leg_2_leg.stl`
- `PART_52_ankle_right_ankle_right.stl`
- `PART_55_ankle_right_foot_right.stl`

用户还应当在尺寸验证通过后，把正式版 `HD1910_REAR_STATOR_ADAPTER.stl` 选择为PA12尼龙。适配片目标数量暂定15件，但用户应当根据单腿试装结果确认最终数量。

嘉立创当前PA12页面给出的工艺为MJF，标称公差为100毫米内±0.3毫米，推荐壁厚为1毫米。大腿加强板 `PART_15` 和 `PART_49` 的模型厚度正好约为1毫米，因此用户应当先打印一件验证，并避免直接批量下单。如果实物刚度不足，设计人员应当把厚度增加到1.5至2毫米，或者改用独立硬质板材。

如果PA12报价或交期不合适，用户可以把3201PA-F尼龙／SLS选择为备选，但用户仍应先打印一个关节验证轴承孔和螺钉孔尺寸。

## 第二组：JLC Black黑色树脂／SLA立体光固化

以下8个外观或精细装配文件可以选择JLC Black：

- `PART_02_trunk_base_right_shell.stl`
- `PART_07_trunk_base_left_shell.stl`
- `PART_30_jaw_soft_face_part.stl`
- `PART_33_jaw_soft_top_head_shell.stl`
- `PART_37_jaw_soft_noenoeil.stl`
- `PART_38_jaw_soft_jaw.stl`
- `PART_39_jaw_soft_bottom_head_shell.stl`
- `PART_40_jaw_soft_m12_lens_holder.stl`

JLC Black适合外壳、外观面和镜头座，并且它能提供比粉末尼龙更细腻的表面。用户如果更看重抗跌落而不是表面效果，也可以把这8个文件统一改选PA12尼龙。

## 第三组：TPU／FDM熔融沉积

以下4个柔性文件应当选择硬度95A的TPU：

- `PART_18_ankle_left_sole_left.stl`
- `PART_31_jaw_soft_jaw_soft.stl`
- `PART_36_jaw_soft_soft_mouth_top.stl`
- `PART_53_ankle_right_sole_right.stl`

嘉立创当前TPU页面给出的默认填充率为15%，材料硬度为95A。用户应当先打印一个鞋底，确认摩擦、回弹和厚度；如果网页自动检查提示最小尺寸或薄壁不合格，用户应当先停止该零件的批量下单，并根据工程审核意见修改模型。

## 不上传的装配占位文件

用户不应上传14个轴承网格、NP-F970电池网格、镜头网格、主控板网格、接口板网格和扬声器网格。用户应当采购这些真实部件。

## 嘉立创网页操作

1. 用户每次最多可以在报价页面同时上传10个模型，并应确保每个文件只包含一个模型。
2. 用户在“材料与规格”步骤为每个模型选择本清单指定的材料。
3. 嘉立创系统会自动检查尺寸、壁厚和重量，工程人员随后会进行人工可打印性审核。
4. 用户在工程审核通过后再次核对文件、材料、数量、颜色、后处理、报价和收货地址，再完成付款。

## 当前参考页面

- 嘉立创下单流程：https://jlc3dp.com/help/article/how-to-place-a-3d-printing-order
- 嘉立创PA12-HP尼龙：https://jlc3dp.com/help/article/pa12-hp-nylon
- 嘉立创3201PA-F尼龙：https://jlc3dp.com/help/article/3201pa-f-nylon
- 嘉立创PA12-CF塑料：https://jlc3dp.com/help/article/pa12-cf-plastic
- 嘉立创TPU：https://jlc3dp.com/help/article/tpu
- 嘉立创JLC Black：https://www.jlc-3dp.cn/materialDetail/282e5458e1724a469e7c802bb7fab2c8.html

---

changed_branch: material_batch_storage
changed_field: jlc3dp_filename_length_limit_50

## 按材质分类存放规则

1. 管理人员只把实际需要打印的模型复制到 `batches`，并把采购件占位模型留在源目录。
2. 管理人员用两位数字固定材料顺序：`00` 表示首件验证，`10` 表示PA12结构件，`20` 表示JLC Black外观件，`30` 表示TPU柔性件。
3. 管理人员在每个材料目录内按嘉立创单次最多10个模型的限制建立 `批次_A`、`批次_B`、`批次_C` 子目录。
4. 管理人员把批量副本的文件名连同扩展名限制在50个字符以内，并在清单的来源路径中保留原始文件名。
5. 管理人员不把不同材质的文件放入同一个上传批次，也不把轴承、电池、主控板、镜头或扬声器占位模型放入上传目录。
6. 操作者先提交 `00_首件验证_PLA-P_FDM`，并在首件通过后再提交PA12、JLC Black和TPU批次。
7. 操作者把 `10_结构件_PA12_MJF` 中的正式适配片数量暂时保留为“待单腿验证，最多15件”，并在验证后填写最终数量。
8. 操作者每次下单前按照 `BATCH_MANIFEST.csv` 核对目录、文件、材料、工艺、数量和放行状态。

## 目录结构

```text
batches/
├─ 00_首件验证_PLA-P_FDM/
│  └─ 批次_A_01件/
├─ 10_结构件_PA12_MJF/
│  ├─ 批次_A_10件/
│  ├─ 批次_B_10件/
│  └─ 批次_C_05件/
├─ 20_外观件_JLC_Black_SLA/
│  └─ 批次_A_08件/
└─ 30_柔性件_TPU_FDM/
   └─ 批次_A_04件/
```

## 放行规则

- 首件验证批次只有在孔位、舵盘、插头、线束和螺钉空间全部通过后才会放行正式结构批次。
- PA12结构批次只有在单关节与单腿通过后才会批量提交。
- JLC Black外观批次只有在外观面方向、颜色和后处理得到确认后才会提交。
- TPU批次只有在一个鞋底完成硬度、摩擦、回弹和尺寸验证后才会提交其余柔性件。
- 任何批次只要出现薄壁、最小尺寸或人工审核问题，操作者就会停止该批次，并只修改被拒绝的模型。

## 文件名长度规则

1. 管理人员把批量上传目录中的每个文件名连同 `.stl` 扩展名限制在50个字符以内。
2. 管理人员保留 `PART_编号` 前缀，并优先删除重复出现的模块名称。
3. 管理人员只重命名批量目录中的副本，并让源模型继续保留原始名称。
4. `BATCH_MANIFEST.csv` 的“文件名”列记录短名称，“来源路径”列记录原始名称，从而保持一一对应关系。
5. 左大腿加强板从 `PART_15_upper_leg_left_upper_leg_rigidity_plate.stl` 缩短为 `PART_15_upper_leg_left_rigidity_plate.stl`。
6. 右大腿加强板从 `PART_49_upper_leg_right_upper_leg_rigidity_plate.stl` 缩短为 `PART_49_upper_leg_right_rigidity_plate.stl`。

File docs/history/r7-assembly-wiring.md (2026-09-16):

> 历史参考：对应旧版硬件/几何；不得视为 R9 当前 BOM、接线或打印放行。

# Microduck 装配布线与紧固件审查 R1

## 打开这个版本
- Blender模型（历史本地资料）
- 内部布线总览（历史本地资料）
- 头部细节（历史本地资料）
- 躯干细节（历史本地资料）
- 外观参考（历史本地资料）
- 紧固件方案用量（历史本地资料）
- 参考线长（历史本地资料）

**当前是已建模的第一轮装配审查版，不是最终打印放行版。**
默认Blender视图隐藏部分外壳以查看内部；外壳没有删除。旧参考方案仍保留在隐藏集合/对象中。

## 本轮实际完成
- 31条机内线束中心线路径及包络，按C01–C12编号；另外建立CSI排线宽度包络。
- 54个与源结构圆孔/舵盘孔圈匹配的M2螺钉候选，4个Pi/HAT叠层螺钉、2个BNO夹座螺钉；合计新增60颗螺钉模型。
- 配套垫片、螺母和隔离件，新增紧固件/隔离件共80个；原ToF两组紧固件保留。
- 7个线束固定点及卡扣试装原型。初版8个候选已归档，最终只保留7个活动候选。
- Pi/HAT托架、BNO夹座、隔离套等共15个闭合试装几何体，并导出STL。
- 原55个PART源网格指纹保持，包括前脸和横条孔。未修改旧源.blend文件。
- 使用已有STEP升级舵机显示网格；碰撞审查仍用保守实体包络，不把参考CAD空心壳体内部当作可布线空间。
- 调整Pi/HAT叠层方向与共同朝向；HAT边界按C1固定版本PCB参考65×30.9mm。NFC模块和两副天线加入候选布置。
- TCA尺寸采用Adafruit2717的30.6×17.6×2.7mm参考；这里需要薄板、免直立排针/低矮引线，实际采购载板仍要匹配。

## 尚未通过的部分
1. 当前采样仍有**2处线束/硬件包络接近或干涉提示、12组线束包络近距提示**，详见MODIFIED_CHECK.json。包络外径尚未按实购线材冻结。
2. CSI排线的宽度/扭转检查仍有标记。它不是只看中心线就能确认的线材。
3. 18个原插头接入点有待核标记；候选出口和实际插头伸出量需要比对。橙色细线只是待确认接入，不代表已完成的实体接线。
4. 159组关节姿态只做端点跨度审查；17条路径仍需进一步考虑运动余量。没有完成真实软线变形/全行程磨擦/疲劳验证。
5. Pi/HAT托架与BNO夹座固定到主体的方法、螺纹啮合与工具空间尚未全部放行。
6. BNO安装方向、HAT方向变化需按实物标定并同步软件外参。本轮没有改运行程序、质量/惯量或控制参数。
7. 配电盒是功能包络，不是已完成的配电PCBA；保护额定、线径、电流预算、板卡实物高度和散热片仍需核对。
8. 新舵机规格图标总厚29mm，而现有参考CAD轴侧包络约30.2mm；本轮螺钉和插头位置仍需用同批实物试装确认。

## 颜色和对象
- RA4_CABLE_：线束包络；F_HORN_/F_HAT_/F_BNO_：紧固件。
- RA4_ENDPOINTS_NEED_CHECK、RA4_REVIEW_FLAGS：接入/近距审查标记。
- RA4_PRINT_FIT_PARTS：试装原型。硬件、导线、PCB和紧固件参考实体不要作为打印件。
- RA4_UNCLASSIFIED_HOLE_SITES：未定螺纹类别的候选孔边界，默认隐藏。

## 文件检查
VERIFICATION.txt（历史本地资料）记录原始哈希、修改字段、基线/修改/回退命令和字面输出。
原始会话包含未保存状态，本轮先保存ORIGINAL_FILE.blend副本。回退只在ROLLBACK_TEST.blend测试，正式修订模型保留。

## 参考资料
- [HAT固定C1版本](https://github.com/pollen-robotics/elec_RPI_Robot_HAT/tree/23eab11927f95ceca0dfa35bf182caeb7db39ea0)
- [Pi Zero 2 W机械图](https://datasheets.raspberrypi.com/rpizero2/raspberry-pi-zero-2-w-mechanical-drawing.pdf)
- [JST EH尺寸](https://www.jst-mfg.com/product/pdf/eng/eEH.pdf)
- [TCA参考板尺寸](https://www.adafruit.com/product/2717)
- [Grove NFC](https://wiki.seeedstudio.com/Grove_NFC/)
- 用户HD-1910新规格书及现有STEP。CAD参考尺寸与新批次实物仍需核对。

## 试装件
print目录只作为试装样件来源；闭合/法向检查不等于已适配硬件、承载可靠或整机可打印。
本包不替代整机原有打印清单，也不表示全部螺丝都需要重新购买。

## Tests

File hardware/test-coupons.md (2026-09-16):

# Mechanical coupon set before full printing

Create one 8–10 mm thick coupon containing:

1. Through holes: 2.0, 2.1, 2.2, 2.3, 2.4 and 2.5 mm.
2. M2 heat-set insert bosses: manufacturer nominal plus +0.10, +0.20 and +0.30 mm.
3. Counterbores: 4.0, 4.2 and 4.4 mm, depths 1.5 and 2.0 mm.
4. Bearing seats:
   - OD 22 mm bearing: 21.8, 21.9, 22.0, 22.1 and 22.2 mm.
   - OD 15 mm bearing: 14.8, 14.9, 15.0, 15.1 and 15.2 mm.
5. Two 1.5 mm cable channels with 3, 4 and 5 mm bend radii.

Record printer, material, nozzle, layer height, wall count, orientation, measured diameter and fit result. Freeze compensation only for that printer/material/process combination.

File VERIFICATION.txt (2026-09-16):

Duck R9 publication verification — 2026-09-16
CHANGED_BRANCH: main (fresh root commit; previous publication history not included)
CHANGED_FIELDS: release_snapshot= r9_2026_09_16; publication_metadata= sanitized; readme.community= included
MODIFIED_FILE: README.md
DIFF_FILE: proof/DIFF_FILE.diff
VERIFICATION: VERIFICATION.txt
ROLLBACK: ROLLBACK.sh
Working directory: repository root. Host executable paths and temporary target paths are normalized below; no personal paths are published.

BASELINE
COMMAND: python tools/verify_publication.py baseline
INPUT: proof/README.original.md
LITERAL_OUTPUT: BASELINE PASS readme=PRE_R9 hash=MATCH
STDERR: 
EXIT_STATUS: 0

ROLLBACK_EXECUTION
COMMAND: bash -c "export PATH=/usr/bin:$PATH; chmod +x ROLLBACK.sh; ./ROLLBACK.sh \"$ROLLBACK_TARGET\""
INPUT: independent copy of current README; ROLLBACK_TARGET is the temporary target
LITERAL_OUTPUT: ROLLBACK_COPY PASS readme=PRE_R9 hash=MATCH
STDERR: 
EXIT_STATUS: 0

ROLLBACK
COMMAND: python tools/verify_publication.py rollback $ROLLBACK_TARGET
INPUT: temporary README copy
LITERAL_OUTPUT: ROLLBACK PASS readme=PRE_R9 hash=MATCH
STDERR: 
EXIT_STATUS: 0

REGRESSION
COMMAND: python tools/test_publication_checks.py
INPUT: 8 synthetic positive/negative privacy tests
LITERAL_OUTPUT: 
STDERR: ........
----------------------------------------------------------------------
Ran 8 tests in 0.000s

OK
EXIT_STATUS: 0

MANIFEST
COMMAND: python tools/verify_publication.py manifest
INPUT: complete sanitized publication tree
LITERAL_OUTPUT: MANIFEST PASS files=94
STDERR: 
EXIT_STATUS: 0

MODIFIED
COMMAND: python tools/verify_publication.py modified
INPUT: README plus complete sanitized publication tree
LITERAL_OUTPUT: MODIFIED PASS stl=39 3mf_parts=11 support=1 privacy_findings=0 links=OK hashes=OK
STDERR: 
EXIT_STATUS: 0

ORIGINAL_README_SHA256: 652e671f66b06f600daa0919746373deb753d7b2647168f19c20f1a644925b8e
MODIFIED_README_SHA256: 7eed4877a084539427fc671c172b758458fd890f4833fafefc4326f533fe8181
RESTORED_STATUS: independent README copy restored byte-for-byte to PRE_R9. Published README remains R9 with community QR. Original workspace files unchanged.
BLENDER: reopened sanitized model; 113 objects, 39 print parts, geometry/transforms/parenting/material assignments unchanged; embedded scripts/images/libraries absent. Fixed-size file-browser directory padding cleared.
3MF: 13 geometry members byte-identical; 11 objects; support remains enabled. Cached thumbnails and slice metadata removed. No slicing or printing was performed during publication.
Earlier preparation checks detected and corrected URL normalization, saved Blender browser metadata, and shell PATH invocation issues; final tests above passed. These checks do not certify physical/electrical readiness.

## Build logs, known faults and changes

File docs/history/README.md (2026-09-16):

# 历史资料索引

以下资料用于追踪决策，不覆盖 [当前 R9 入口](../../README.md)。旧本机链接已转为文字提示，原采购订单、商家聊天和本机附件不公开。

- [R3 硬件选型](r3-hardware-selection.md)
- [R4 实施计划](r4-implementation.md)
- [R5 树莓派迁移](r5-migration.md)
- [R6 接线历史](r6-connections.md)
- [R7 装配/接线](r7-assembly-wiring.md)、[线长](r7-cable-lengths.md)、[紧固件](r7-fastener-schedule.md)
- [R8 螺丝审核](r8-fastener-audit.md)、[采购备料参考](r8-purchase-reference.md)
- [材料参考](material-guide.md)

未将旧整机 Blender、重复 ZIP、回滚测试模型、采购 Excel、截图及第三方源码镜像重复上传。旧 Rev A 文档仍位于 docs 根目录；上游代码保留链接和版本锁。

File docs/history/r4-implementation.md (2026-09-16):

> 历史参考：对应旧版硬件/几何；不得视为 R9 当前 BOM、接线或打印放行。

# Microduck R4 实施方案

更新：2026-09-05。HD-1910-C001 按用户已购处理。本轮核到8个实际商品详情页；整机采购、PCB和3D模型尚未定稿。

## 1. 主控降成本

**优先目标：Radxa ZERO 3W 2GB RAM＋16GB eMMC，带已焊40针排针。**

其次考虑同款2GB、无eMMC版本，另配32GB以上microSD。维持RK3566、ZERO 3W和原有接口方向，不把同名的Orange Pi Zero 3W混进来，也不因便宜直接换ZERO 3E。

- 官方列有1/2/4/8GB内存及多种eMMC配置，统一板框65×30mm。仍需核所发PCB版号、排针、连接器和散热器高度。[Radxa规格](https://docs.radxa.com/en/zero/zero3)
- 本地运行代码采用Rust服务与50Hz控制，策略文件约0.76MB；这不等于总运行内存只有0.76MB。2GB是成本优先的验证目标，不是已经做过整机RAM测试的结论。[项目说明](https://github.com/pollen-robotics/microduck)
- 用精简系统，把训练放在电脑上；在板上验证控制循环、摄像头和音频同时运行的内存及延迟。
- 当前核实的芯板坊商品实选是“单板＋8G/64G”，优惠前1169元、页面显示有货。低配选项存在禁用状态冲突，尚未落实低价供货，因此**不默认采购这块8GB高配板**。
- 主控页：[芯板坊 ZERO 3W](https://item.taobao.com/item.htm?id=746425059858)。此链接未固定高价SKU；目标低配仍需卖家回执。

## 2. 已落实的商品入口与取舍

| 部件 | 本轮选择或候选 | 商品证据与购买注意 |
|---|---|---|
| 散热 | Radxa 5519A | [瑞莎计算机店](https://item.taobao.com/item.htm?id=788387010174&skuId=5551969955434)，页面19.99元、有货。总安装高度待补。 |
| 相机 | Radxa Camera 8M 219 | [瑞莎计算机店](https://item.taobao.com/item.htm?id=768918125679&skuId=5272733244281)，选适配3W/3E套餐，129.99元、有货。 |
| IMU | 龙邱 LSM6DSV16X模块候选 | [商品页](https://item.taobao.com/item.htm?id=712929048404&skuId=6260052678408)，所选SKU正确且显示有货，43元；共用参数栏写LSM6DSR，需核该SKU实际板卡、接口和尺寸。 |
| 测距 | 优信/Your Cee VL53L8CX模块候选 | [商品页](https://item.taobao.com/item.htm?id=964622483389)，81.5元、有货，页面列92133.PDF；载板电路和尺寸待补，不沿用Pololu载板尺寸。 |
| 音频 | Waveshare WM8960 Audio HAT成品优先方案 | [微雪旗舰店](https://detail.tmall.com/item.htm?id=610674584337&skuId=6089138957530)，所选为Audio HAT，优惠前114元、有货。不是便宜的WM8960裸模块。 |
| 充电 | SkyRC B6neo | [天空创新科技店](https://item.taobao.com/item.htm?id=720907211471&skuId=5021215501904)，195元，但写明预售15天；电源和充电线另核。 |
| 急停 | IDEC XA1E-BV302R目标选项 | [商品页](https://item.taobao.com/item.htm?id=992384868571)，确有302R选项；搜索默认选的是“其他型号联系客服”，77元不是302R已核报价。 |

以上为读取时的页面信息，不含运费；价格和交期以最终选项为准。未执行加购、下单或付款。

## 3. 减少自制板和重复采购

首版音频优先采用WM8960成品HAT，替代原AUDIO-HAT-R3自制路线。它有板载双MEMS麦克风、I2S编解码和8Ω负载1W/路输出。采用此路线时取消单独购买CMC-4015-25T及Samtec排母；板载麦克风不接到外部3.5mm插口。[官方功能与接口](https://www.waveshare.com/wiki/WM8960_Audio_HAT)

**该HAT并非已在Radxa上验证即插即用。**官方树莓派安装脚本不直接套到RK3566；需适配音频设备树、I2C/I2S时钟、ALSA设备名，再验证录放音。

配电板仍需定制：舵机TTL、逻辑/舵机分路、欠压、急停默认关闭与手动重使能、回馈尖峰及数字3.3V辅助电源。WM8960板不替代这些保护功能。原34×42mm仅为空间目标，完成电路和布局后再定板框、孔位和PCBA加工资料。

套装8Ω扬声器先作为机外音频调试件；其尺寸尚未核对，不直接当作原来的20mm在机喇叭。

## 4. 已发现并修订的引脚冲突

- WM8960 HAT按钮接树莓派BCM17，即40针**物理11脚**；它与旧方案在11脚上的软件禁能信号冲突。
- 新方案将软件禁能候选移到**物理36脚 / GPIO3_A7**；电路必须在断电或GPIO高阻时保持舵机关闭，最终电平极性由原理图确认。
- **物理13脚预留MCLK**，不再随意占用。HAT有24MHz时钟，完整时钟树仍需驱动验证。
- 音频固定接口：I2C物理3/5；I2S物理12/35/40/38。按选定Radxa内核确认控制器及overlay。
- 躯干IMU仍预留I2C4物理27/28；不进行USB改线。NFC预留UART4、UART5。所有GPIO信号以3.3V为设计基准。
- UART2物理8/10默认兼任控制台，必须处理引导干扰后再接舵机总线。[Radxa引脚与控制台说明](https://docs.radxa.com/en/zero/zero3/hardware-design/hardware-interface)

完整候选针脚分配保存在本轮数据文件中，数字针脚无重复。这是规划检查，不替代接线和实机验证。

## 5. 机械工作已补充的依据

- WM8960官方尺寸图：板框65×30mm，孔距58×23mm；孔径及安装公差另核。
- 已下载[官方3D资料](https://files.waveshare.com/upload/b/b3/WM8960_Audio_HAT_drawing.zip)，解析其中STEP得到外包络 **65.4×31.95×18.9mm**。不要再用1.6mm PCB板厚代表完整板卡总高。
- 相机仍按32×32mm板、28×28mm孔距及真实镜头/FPC座适配。
- 龙邱IMU、优信ToF需各自的载板尺寸；原SparkFun、Pololu安装座尺寸不继续套用。
- 电池实际淘宝型号尚未落实，因此电池托、绑带、插头退出空间不做最终尺寸锁定。
- RA2 Blender及37个原型STL本轮未改动。PR31可和首套原型同批打印，不强制分开下单；整套打印应在同版硬件适配完成后统一安排。

## 6. 现在剩下的具体工作

1. 找到可供的ZERO 3W低配SKU及价格，避免因单个现货结果而默认升到8GB。
2. 落实2S电池、5V模块、在机小扬声器和HD原厂线束/调试器。零搜索结果不视为全淘宝缺货结论。
3. 核IMU/ToF具体载板图、散热总高与紧固件；从最终商品一次收齐资料。
4. 完成WM8960软件适配与定制配电板设计，再统一更新整机模型、线束和开孔。
5. 输出同一版本的最终BOM与整套STL，并做配合、运动和电气测试。

本轮后段的部分商品页再次转到淘宝登录页，这些页面按“未核验”处理，没有当作商品资料写入已确认项。

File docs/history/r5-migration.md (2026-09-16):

> 历史参考：对应旧版硬件/几何；不得视为 R9 当前 BOM、接线或打印放行。

# Microduck：树莓派 Zero 2 W 完整迁移方案

**方案版本：R5。主控改为 Raspberry Pi Zero 2 W，保留已购15个HD-1910-C001。**

本文确定硬件路线、任务分工、接线、软件移植范围、机械修改和验收顺序。当前交付的是迁移设计与静态核对结果；软件尚未移植完成，配电PCB尚未投板，RA2模型尚未改成树莓派整机版。

## 一、最终采用的路线

| 项目 | R5选择 |
|---|---|
| 主控 | Raspberry Pi Zero 2 W，512MB，40PIN排针已焊接；不是老Zero/Zero W，也不是Orange Pi |
| 系统 | Raspberry Pi OS Lite 64-bit，无桌面；验收后锁定镜像及内核版本 |
| 存储 | 正品microSD 32GB以上，另留整卡备份 |
| 运动控制 | 本机50Hz；HD舵机后端＋独立I2C IMU；网络不参与每一帧闭环 |
| 相机 | Raspberry Pi Camera Module 2标准可见光版＋Camera Standard–Mini排线 |
| 音频 | Waveshare WM8960 Audio HAT，保留板载双MEMS麦克风 |
| 重视觉、ASR/TTS、大模型 | 电脑或云端运行，只回传高层意图/音频；不在512MB板上训练 |
| 供电 | 标准LiPo 2S；舵机原电池电压，Pi及音频走独立5V逻辑支路 |
| 定制件 | 一块PWR-PI-R5配电/TTL/保护板＋整机打印结构 |

Zero 2 W是四核64位A53、1GHz、512MB、65×30mm，具备相机接口和H.264编码能力。[主控官方规格](https://www.raspberrypi.com/products/raspberry-pi-zero-2-w/)

**这条路线有原型依据**：项目的`deploy/robotd.toml`注明，50Hz最初是在Raspberry Pi Zero 2W原型上选定的。不过当前软件已增加Rockchip专用媒体代码，且你的舵机换成了HD1910，旧原型经验不等于本机已经验收。[项目参数说明](https://github.com/pollen-robotics/microduck/blob/main/deploy/robotd.toml)

## 二、哪些功能保留，哪些处理放到外部

| 功能 | 执行位置 | 迁移后的要求 |
|---|---|---|
| 15舵机控制、姿态、跌倒检测 | Pi本机 | 固定50Hz，使用有效反馈；故障时停止使能 |
| 手柄与基础动作、离线叫声 | Pi本机 | 保留BlueZ和本地音效，不依赖网络才能站住 |
| 相机采集与视频传输 | Pi本机采集/编码 | 初版640×360、15fps、约1Mb/s，保持16:9；验证后再提高 |
| 麦克风采集、播放TTS | Pi本机音频接口 | 采用ALSA稳定卡名，初版低音量测试 |
| ToF、两处NFC交互 | Pi慢外设进程 | 独立于IMU总线和运动循环，故障不阻塞控制线程 |
| 目标识别、复杂语音理解 | 电脑/云端 | 低频图像/音频上传，返回意图；不直接发送每帧关节角度 |

远端断连时取消远程运动意图，回到本机可控状态；媒体服务崩溃不能带走控制进程。RKNN模型不在Pi上直接加载；如尝试CPU识别，必须限频并验证资源余量。该方案不宣称离线重视觉性能与RK3566版本相同。

## 三、采购清单的保留、更换与新增

### 直接保留的方向

- **HD-1910-C001：15个，新增采购0。** 原厂舵盘、壳体螺钉和线束先按已购套装复点。
- **WM8960 Audio HAT：1块。** 已取得微雪商品入口与官方尺寸资料，保留此成品路线，不再自制AIC3104音频板。
- **LSM6DSV16X IMU：1块，安装在躯干。** 龙邱模块是当前候选，要求该SKU的板框、针序与芯片实拍，排除同页LSM6DSR款。
- **VL53L8CX ToF：1块。** 优信载板是当前候选，供电/IO电平以载板电路为准，不套用Pololu模块尺寸。
- **标准LiPo 2S电池、B6neo充电器、IDEC 2NC急停**继续使用既定方向。电池实供型号、充电线和准确急停SKU仍须落实。

### 更换或新增

| 采购项 | 数量 | 规格与避免误买的重点 |
|---|---:|---|
| Pi Zero 2 W主板 | 1 | 要2W、512MB、四核，要求已焊40PIN；“2WH”常是卖家对已焊针款的名称 |
| microSD与读卡器 | 1套 | 32GB以上；不把原Radxa的eMMC方案继续算入 |
| 低矮散热片 | 1 | 15×15×5mm为设计目标，绝缘导热胶固定，后续核HAT下净空 |
| Camera Module 2标准版 | 1 | 官方IMX219模组，非NoIR；撤下未采购的Radxa 32mm模组目标 |
| Camera Standard–Mini排线 | 1 | 200mm，15针标准端到22针Mini端；相机线，不是显示屏线 |
| TCA9548A复用模块 | 1 | 3.3V、A0/A1/A2接地、RESET可引出；解决两PN532同地址 |
| Micro-USB线＋OTG短转接 | 1套 | Pi接口不是USB-C；Wi-Fi/SD卡部署优先，不需要持续插电脑USB |
| Pi台架电源 | 1 | 官方12.5W Micro-USB，5.1V/2.5A，插头版本按使用地区选择；已有合适电源可复用 |
| 5V稳压模块 | 1 | R5指定D24V50F5作为技术路线；具体供货/报价另核，不沿用S13V30F5板框 |

**淘宝核验结论**：已检索到多个Pi商品入口，但一个169元混售链接实际选中的是老款ZERO，其Zero 2 W选项存在禁用标记冲突；该169元未作为2W价格写入预算。另一候选详情未完成读取。目标型号已经锁定，精确SKU价格和库存仍单独核验；不使用搜索最低价假装全套报价。

外置CMC麦克风、单独Samtec排母取消，采用HAT集成部分。套装扬声器的尺寸尚未核实，仅作为机外台架喇叭；在机扬声器按8Ω、约20mm、额定≥1W目标另核尺寸，接HAT一组BTL输出，负端不接地。

## 四、供电与保护设计

```text
标准2S电池（满电8.4V）
  └─主保险丝─┬─逻辑保险丝─逻辑欠压关断─D24V50F5─5V_LOGIC─┬─Pi
              │                                           ├─WM8960 HAT
              │                                           └─3.3V_AUX─传感器/NFC
              └─舵机受控开关─三路保险丝─每路5个HD舵机

舵机受控开关的使能条件：
硬件ARM锁存 ∧ 急停NC1闭合 ∧ 电压正常 ∧ 看门狗正常 ∧ Pi使能 ∧ 无故障锁存
```

1. **舵机电源不经过Pi、GPIO、音频HAT或调试板的细走线。** 大电流在配电板分配，控制信号共地。
2. D24V50F5是固定5V模块，典型输出能力受散热影响。官方给出的最低输入为轻载约6V、5A时约6.2V；R5逻辑支路以输入不低于6.4V为设计边界。[稳压器规格](https://www.pololu.com/product/2851/specs)
3. 5V逻辑负载按2.5A设计目标验证，3.3V辅助支路按1A容量规划；这不是已测功耗。3.3V_AUX从5V_LOGIC产生，**不与Pi的1/17脚3.3V输出并联**。
4. 初版包电压目标：6.8V预警并准备关机、6.6V停止舵机、6.4V逻辑硬截止。实际阈值需结合电池压降、精度与电芯要求复核，另做逐节欠压/失衡检测；总电压不替代逐节保护。
5. 保险丝初值沿用主15A、三路舵机各5A、逻辑输入3A，最终依电流波形、I²t、铜箔与线温确定。它们不是精确电机限流器。
6. 急停NC1进入硬件关断链；NC2只提供状态反馈。释放急停或恢复通信后仍需手动ARM，软件不得自动重使能。
7. 心跳由控制线程在完成一次受控状态机周期后产生，初版10Hz、独立硬件看门狗300ms超时为设计目标。待机时允许心跳；电机供电后另以反馈时效判断故障，避免“没反馈就不给电、没电就没反馈”的启动死锁。普通定时器不代喂。
8. 反接、短路、再生回馈及断电尖峰都需设计和波形验证。**回馈钳位器件不在缺少HD允许瞬态电压资料时随意定型**；原SMBJ12A等旧占位不自动沿用。
9. 用Micro-USB台架电源前，物理断开机内5V支路；两路5V不直接并联。充电时电池从机身取下，使用标准LiPo 2S平衡模式，而非LiHV。
10. 电机电源关闭时，TTL驱动和DATA上拉同步关闭/隔离，防止经信号线向未供电舵机反向供电。

### 上电与扭矩使能分开

`SAFE_OFF → LOGIC_READY → POWERED_CHECK → TORQUE_ENABLED`，任一故障进入锁存的`FAULT_LATCHED`。

- 待机先完成Pi、IMU、看门狗与接口检查，电机电源保持关闭。
- 手动ARM后允许电机电源进入最长1秒的上电预检窗口；**先验证HD舵机上电默认扭矩关闭**，完成ID/反馈检查并设置保持目标。资料未确认时，只在固定台架完成这项验证。
- 预检通过后，由用户再次明确使能才允许扭矩/动作；电机上电不等于开始行走。
- 超时、错ID、反馈陈旧等均关电并锁存；恢复条件后也不自动跳回使能状态。

**PWR-PI-R5仍需原理图、布局和PCBA。** 本方案没有把这块定制电源板伪装成淘宝现货，也未生成可直接投板的Gerber。

## 五、完整接口与引脚分配

以下为**40针物理编号**；BCM编号另列。外设线由装配方从Pi对应焊盘引出，绝缘并固定，避免HAT下方硬挤杜邦插头。

| 物理针脚 | BCM | 用途 | 去向 |
|---|---|---|---|
| 2、4 | — | 5V_LOGIC | Pi/HAT供电 |
| 1、17 | — | Pi的3.3V端 | 保留，不并接辅助稳压器 |
| 6、9、14、20、25、30、34、39 | — | GND | 逻辑信号公共地 |
| 3、5 | 2、3 | 硬件I2C1 | IMU＋WM8960控制 |
| 8、10 | 14、15 | UART0 TX/RX | 经TTL半双工收发电路到HD总线 |
| 12、35、40、38 | 18、19、21、20 | I2S | BCLK、LRCLK、DAC数据、ADC数据 |
| 11 | 17 | HAT按钮 | 只作输入 |
| 15、16 | 22、23 | 软件I2C3 | ToF＋NFC复用器 |
| 18 | 24 | 急停状态 | NC2反馈，断线产生故障状态 |
| 22 | 25 | IMU中断预留 | 载板有INT时接 |
| 29 | 5 | 复用器RESET_N | TCA9548A复位 |
| 31 | 6 | ToF复位预留 | 载板引出LPn时接 |
| 36 | 16 | SERVO_ENABLE | 高有效设计，外部下拉，默认OFF |
| 37 | 26 | 控制心跳 | 配电板独立看门狗 |
| 7 | 4 | BAT_LOW | 电压监测状态，GPIO侧只接3.3V |
| 27、28 | 0、1 | HAT识别保留 | 不接IMU |
| 13、19、21、23、24、26、32、33 | 27、10、9、11、8、7、12、13 | 暂不使用 | 不再标为Radxa UART4/5或MCLK |

### 串口与蓝牙

Zero 2 W没有原Radxa路线的UART4、UART5。采用`miniuart-bt`将蓝牙换到mini UART，释放PL011给物理8/10，使用`/dev/serial0`；固定VPU核心时钟250MHz。蓝牙吞吐会受影响，需测试手柄和BLE并行稳定性，不默认关闭蓝牙。[官方UART说明](https://www.raspberrypi.com/documentation/computers/configuration.html#configure-uarts)

HD总线目标先按1Mbps做带宽预算，但波特率、包格式和寄存器必须由本批舵机资料确认。Pi GPIO不直接当作舵机电源或任意5V总线输入；TTL接口需要方向/回波处理和电平验证。

### I2C地址与两路NFC

| 总线 | 器件 | 7位地址 | 要点 |
|---|---|---|---|
| `/dev/i2c-1` | WM8960 | 0x1A | 初始化与低频音量控制 |
| `/dev/i2c-1` | LSM6DSV16X | 0x6A或0x6B | 核芯片ID及载板跳线；固定坐标变换 |
| `/dev/i2c-3` | VL53L8CX | 0x29 | 固件加载/测距在慢外设进程 |
| `/dev/i2c-3` | TCA9548A | 0x70 | A0/A1/A2接地 |
| MUX通道0 | 头部PN532 | 0x24 | 单独通道 |
| MUX通道1 | 嘴部PN532 | 0x24 | 单独通道 |

Grove PN532默认UART，需按模块版本改为I2C；可让供货方完成跳线并验收。两个同地址设备不直接并到一条总线上。[Grove接口说明](https://wiki.seeedstudio.com/Grove_NFC/) · [TCA9548A资料](https://www.ti.com/product/TCA9548A)

MUX由Linux驱动/单一外设管理进程控制，每次只选通一个NFC通道。子总线编号通过`/sys/bus/i2c/devices/3-0070/channel-*`发现，不硬编码为i2c4/5。总线故障时先停止相关事务，再复位MUX、重建驱动状态并重新枚举，避免缓存仍以为旧通道已选中。

IMU读取在硬件总线；ToF初始低频（例如5Hz）和NFC轮询在独立软件总线。软件I2C速度需要实测；任何慢外设调用都不得阻塞50Hz控制线程。

## 六、系统配置与启动顺序

1. 用Raspberry Pi Imager选择Zero 2 W及Lite 64-bit，写入SD卡。设置Wi-Fi和SSH，不在板上安装桌面环境或编译大型依赖。
2. 先备份`/boot/firmware/config.txt`、`cmdline.txt`及整卡镜像。保留现有图形配置，仅合并附件中的配置片段。
3. 检查所选镜像是否提供`wm8960-soundcard`和`i2c-gpio` overlay；若缺少，按当前内核匹配官方/厂商支持，不混装两套音频驱动。
4. 移除`cmdline.txt`中的串口控制台项，但保持其他启动参数和单行格式；释放UART给舵机。
5. 先逻辑供电，确认音频、相机、I2C与串口，再接电机电源。整个准备阶段SERVO_ENABLE保持低。

配置核心如下；完整带注释版本见同目录文件。WM8960官方原理图中XTAL1为24MHz，而树莓派overlay默认时钟可能不同，因此显式指定并核实所发板卡。[HAT原理图](https://files.waveshare.com/upload/f/fa/WM8960_Audio_HAT_Schematic.pdf) · [官方overlay参数](https://raw.githubusercontent.com/raspberrypi/firmware/master/boot/overlays/README)

```ini
dtparam=i2c_arm=on
dtparam=i2c_arm_baudrate=400000
dtparam=i2s=on
enable_uart=1
dtoverlay=miniuart-bt
core_freq=250
dtoverlay=i2c-gpio,bus=3,i2c_gpio_sda=22,i2c_gpio_scl=23,i2c_gpio_delay_us=2
dtoverlay=wm8960-soundcard,alsaname=wm8960,mclk=24000000
camera_auto_detect=1
```

控制心跳与使能GPIO由移植后的控制状态机独占；普通定时器或媒体进程不代喂看门狗。I2C复用器需在慢总线注册，随后枚举子总线；其驱动绑定与故障恢复属于外设进程的实现工作。

## 七、软件迁移任务清单

| 现有位置 | R5要做的改动 | 验证方式 |
|---|---|---|
| `duck-control/src/bus.rs` | 从硬编码XL330/Dynamixel寄存器中抽离`Hd1910Io`；实现本批协议、量纲、限位、回波和错误处理 | 原厂帧样本单测；单舵机后再15台负载与错误注入 |
| `duck-control/src/imu.rs`及`io.rs` | 增加LSM6DSV16X I2C/SFLP FIFO读取，接入原`ImuData`；删除对ID200同步应答的依赖 | 轴向、量纲、四元数归一化、陈旧样本与断线测试 |
| `robotd-params`、`deploy/robotd.toml` | 增加Pi板型配置；串口`/dev/serial0`、ALSA`plughw:wm8960`；配置版本可追踪 | 解析及往返测试，保留旧平台配置兼容性 |
| `mediad/src/pipeline.rs`、`producer.rs`、`exposure.rs` | 增加Pi媒体后端，替换rkisp/MPP及Rockchip曝光逻辑；使用libcamera/rpicam与Pi硬件H.264 | 独立视频测试，再集成WebRTC、音频与控制 |
| `robotd-params::Quality` | 增加`360p15`及匹配尺寸/帧率/码率，保留现有16:9约定 | 更新枚举、列表、解析、尺寸、码率测试；旧代码只有360p30等档位，尚无360p15 |
| `kinematics`及媒体帧元数据 | 重标Camera Module 2内参、裁剪后的视场及相机到头部的安装变换 | 重核坐标旋转，不盲用旧90°旋转或Radxa相机标定 |
| `duck-detect`、`pet-detect` | 默认关闭板端重识别；使用电脑/云端服务，或另做低频CPU模式 | 验证超时不会阻塞机器人，远端只下发高层意图 |
| `tof`与新NFC外设进程 | 使用慢I2C3、MUX子总线、有限超时；媒体和运动读取缓存结果 | 模块掉线/总线锁死时IMU与控制继续满足时序 |
| `btd/configd/padd` | 保留BlueZ；撤下Radxa AIC8800特有启动修复脚本，重验Pi蓝牙配对 | 手柄＋BLE＋Wi-Fi视频同时测试 |
| `scripts/setup-board.sh`等部署脚本 | 新增Pi配置分支，不运行Radxa的rsetup、rkisp/NPU安装；ARM64依赖在电脑上构建 | 独立Pi发布通道、签名/哈希/健康检查和回滚测试 |

**当前源码的默认相机质量、串口和音频设备仍偏向Radxa。只改串口路径不足以让HD舵机和相机工作。**已有`.rknn`不在Pi加载；ONNX运动策略保持本地，但舵机、质量、惯量和安装改变后仍须辨识/再训练或验证。现有51维/61维策略也须按运行时接口检查。

先单独用`rpicam`证明Camera Module 2的硬件采集/编码，再接WebRTC。初版640×360、15fps不写成已达成性能；它需要新质量档位和真实媒体后端。[Pi相机软件](https://www.raspberrypi.com/documentation/computers/camera_software.html)

## 八、机械模型修改清单

| 部位 | 必做事项 |
|---|---|
| Pi安装座 | 原场景有Pi Zero 2 W历史参考对象，可用于定位；按真实Pi板与已焊排针重新核尺寸，不把旧平板占位当完整装配 |
| 头壳/底壳 | USB-C方案改为Micro-USB；检查Mini HDMI及SD卡退出方向，不沿用Radxa连接器开口 |
| Pi＋HAT叠层 | WM8960官方STEP包络为65.4×31.95×18.9mm；连接器插入部分只计算一次，叠层总高按实际总装上下极值确定 |
| 相机托/面板 | Camera Module 2官方参考约25×24×9mm，替换32mm Radxa相机座；重核光轴、镜头外露、排线座与视场 |
| 散热与导声 | 低矮Pi散热片不触及HAT焊点；两个MEMS麦克风的声孔与风道避开电机和热源 |
| 躯干 | IMU刚性固定；PWR-PI-R5、电池托、MUX及线束按具体外形排布，不凭芯片型号推定载板尺寸 |
| 线束 | UART、I2S/音频和电源回路分区，关节全行程不拉扯、不夹线；所有插头计算完整对接与拔插空间 |
| 急停盒 | 首版保持外置有线盒，急停和ARM可操作；线断会失能，线缆有拉力缓冲 |

当前RA2的37个STL仍是参考原型（36件结构＋1件PR31试块），不是R5整机打印包。你希望减少分批操作，因此**先统一完成R5布局与核对，再统一安排首套打印**；PR31可随首套同批。到货检查、装配与负载测试仍保留。

## 九、按阶段执行，避免反复改方案

| 阶段 | 交付物 | 进入下一步的条件 |
|---|---|---|
| M0 资料冻结 | 正确Pi SKU、Camera2/排线、IMU/ToF载板图、HD协议/附件、电池与接头资料 | 型号和接口无歧义；不再按搜索最低价定购 |
| M1 Pi系统与外设 | 固定镜像、配置片段、外设枚举日志 | 串口/音频/相机/两条I2C正常，舵机未使能 |
| M2 HD与IMU驱动 | 协议单测、驱动、台架数据 | 扭矩开关、零位/方向、反馈和故障处理通过 |
| M3 配电设计 | 原理图、PCB、BOM、贴片坐标及保护测试记录 | 电压、电流、温升、回馈、欠压、急停/看门狗通过 |
| M4 统一机械适配 | R5装配模型、完整线束、逐件STL | 孔位、紧固件、壁厚、插拔和全行程复核通过 |
| M5 一次采购/制造批次 | 最终BOM、整套打印清单、PCBA加工包 | 未决型号与数量已清零；明确现货/预售交期 |
| M6 整机验证 | 标定、称重/惯量、运动与音视频并发日志 | 按下表验收后，才形成可复用的成品方案 |

上述是执行顺序，不要求每一步都买一轮硬件；主控、相机和音频等标准件可并成一单，配电和外壳在设计冻结后统一制造。舵机保持已购，不重复采购。

## 十、验收目标与失败处理

以下数值是本方案的工程验收目标，不是已测结果或官方保证：

- 控制目标50Hz，30分钟并发测试中平均≥49Hz、周期p99≤25ms；记录总线错误和最长停顿。
- 连续无有效电机/IMU反馈超过100ms进入失能处理；独立看门狗覆盖控制线程完全卡死。
- 内存`MemAvailable`保留至少80MB目标，不持续换页；先限媒体/识别负载，不通过压低保护要求掩盖性能不足。
- CPU持续温度目标低于75°C，记录降频/欠压标志；Pi输入端5V测试目标4.85–5.20V。
- 检查15个ID、转向、零位、关节限位和角度/速度/电流量纲；舵机总线不是Dynamixel寄存器表的简单重命名。
- 验证急停按下、线断、断电重启、故障恢复：电机默认OFF，释放急停后不自动启动；Pi逻辑电源保持到正常关机或低压硬截止。
- 验证ToF/MUX/NFC故障不会锁住实时IMU路径；网络/媒体失联只影响远端功能，不替代本机故障保护。
- 先悬挂、单关节/单腿，再受控地面运动；旧策略不因文件能加载就视为适配HD电机。

如果Zero 2 W在上述任务分工下仍达不到控制时序或内存目标，先收缩本地媒体/识别负载并保留远端处理；仍不满足时进入明确的Pi更高配主控评审，而不是继续采购并假定能跑。

## 十一、附件与当前完成状态

- 机器可读迁移规格（历史本地资料）：完整针脚、电源域、I2C地址、任务分工和未决项。
- 启动配置片段（历史本地资料）：需在选定Pi镜像上验证后合并，不替换整个配置文件。
- 只读上机检查脚本（历史本地资料）：检查板型、64位系统、串口、I2C、音频、相机与温度，不使能电机。

已完成：R5迁移设计、针脚/地址一致性检查、负面案例检查、采购与打印依赖更新。

未完成：正确Pi SKU的最终供货确认、HD协议回执、配电PCB、代码移植、R5 Blender模型、实机验收。当前不宣称整套可直接下单打印，也不把未经验证的树莓派镜像作为成品交付。

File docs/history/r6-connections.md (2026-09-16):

> 历史参考：对应旧版硬件/几何；不得视为 R9 当前 BOM、接线或打印放行。

# 全硬件连接核对依据

本轮按对话最新选择绘制：Pi Zero 2 W、RPI Robot HAT C1（23eab119）、15个HD-1910-C001、BNO085、已购VL53L8CX载板、套装CSI摄像头、20mm/1W喇叭、自定义双位置PN532 NFC、TCA9548A、NTAG213标签、2S850mAh35C持续XT30电池、BC-4S15D充电器套装及URT-1调试工具。旧采购表中的B6neo与NFC待官方确认备注没有作为当前依据。

## 图1：机内运行

采用最近讨论的基本架构：同一2S电池分出舵机动力与HAT逻辑支路。保险/总开关/欠压与分路配电是功能要求，额定值与实供组件未定，不将PROTECT-R6画成已存在的必购板。独立受控动力关断如需保留，仍需另完成实现；本图不宣称已实现。

| ID | 来源 | 去向 | 核对状态 |
|---|---|---|---|
| P01 | 2S电池XT30正负两线 | 保险、总开关与适当保护，再分路配电 | 拓扑确认；器件额定、导线长度/线径、端子电流待定 |
| P02 | 保护后的2S正极 | HAT J14.2 +BATT | C1原理图核对 |
| P03 | 电池公共负极/GND | HAT J14.1 GND | C1原理图核对 |
| P04 | J14.3 | 留空，不接充电器或GPIO | 该针为TTL DATA，本连接中不用 |
| P05 | 动力分路配电正极 | HD-1910每个接口的2 VCC | 新舵机PDF确认；应足额多点配电，不以一只HAT插头带15个舵机 |
| P06 | 动力公共负极/GND | HD每个接口的3 GND | 新舵机PDF确认 |
| D01 | HAT J13.3 DATA | HD每个接口的1 DATA，共享总线 | C1及HD资料确认；HD驱动仍需适配 |
| D02 | HAT J13.1 GND | 舵机/配电公共地 | 共地，不将大电流回流压到信号线 |
| D03 | J13.2 +BATT | 在这条通信线束内留空 | 板上该脚本身仍带电；避免绕过独立配电 |
| H01 | HAT J4 2×20排母 | Pi Zero 2 W的40针排针，2.54mm间距 | 官方BOM确认。HAT→Pi为5V供电，UART/I2C/I2S通过同一连接 |
| H02 | HAT J1两端 | 喇叭两根引线 | PAM8406桥接输出；两端均不接公共地；1W喇叭需限幅，8Ω仍需核实订单 |
| H03 | HAT板上MEMS麦克风、BMI088 | 板内连接，经J4到主控 | 不增购第二块麦克风/头部IMU，首版以躯干BNO为平衡反馈 |
| S01 | Pi CSI | 已购套装摄像头，使用匹配Zero的排线 | Pi端为Zero CSI；摄像头具体传感器/排线另一端未确认，不写成已购原厂IMX219 |
| S02 | Pi microSD槽 | 已购32GB microSD卡 | 卡槽连接 |
| S03 | 蓝牙手柄 | Pi蓝牙 | 无线连接，无供电线接Pi |
| S04 | Pi I2C1，BCM2/3（物理3/5） | BNO085载板SDA/SCL | 连接规划。具体载板VCC/IO、模式/INT/RST待商家资料；不将另一品牌载板的电气条件套用 |
| S05 | Pi规划软件I2C，BCM23/27（物理16/13） | VL53L8CX载板与TCA9548A上游SDA/SCL | 新总线需配置，非现成默认总线；从GPIO焊盘/适配引出，HAT J6/J7/J8不是同一I2C口 |
| S06 | VL53L8CX载板 | 电源/IO/接口模式/LPn/INT | 待载板资料。裸芯片AVDD3.3V但IO1.2/1.8V，图中不画作确定3.3V GPIO直连 |
| N01 | TCA9548A CH0 | 头部Grove PN532（SKU113020006） | 规划；模块改为I2C模式 |
| N02 | TCA9548A CH1 | 嘴部Grove PN532（同款） | 规划；两同地址设备不同时开通MUX通道 |
| N03 | Pi 3.3V/GND支路 | TCA9548A与两个Grove PN532 | Seeed明确模块工作电压3.3V；合计读写电流约166mA，需计入Pi3.3V预算 |
| N04 | 每个PN532 | 自己的配套分体天线；各天线无线读NTAG213标签 | 不交叉连接天线；不用官方墨水屏协议 |
| N05 | PN532两处射频场 | 软件交替控制 | 切MUX仅隔离I2C，不关射频场；需软件关场轮询，验证相互干扰 |

HAT端线插为EHR-3（EH2.5mm3针）；HD端按厂家称谓AMP2.0-3P。图上针号是电气针号，不是从任意方向观察插头的左右顺序。引脚位置还应依据实际连接器针1标记确认。

## 图2：充电、调试与烧录（互斥/独立场景）

1. 充电：随箱12V适配器→BC-4S15D的DC输入。2S电池三线平衡插头→充电器2S口，具体插头及顺序待实物确认。电池XT30与机器人断开；鳄鱼夹线是输入侧备用线，不是给电池充电的输出线。暂不为该充电方式买XT30主充电线。同型号说明书给1.5A，对850mAh为约1.76C；先核电池允许充电电流，35C是放电规格。
2. 舵机调试：电脑USB数据→URT-1 Mini-USB。独立7.4V限流电源（或合适2S电源，二选一）→URT-1 TTL/SCS侧V/G电源端子。URT TTL/SCS 5264-3AW→对应AMP2.0-3P转接线→单个HD舵机，按S/V/G对接。USB并不提供舵机动力；URT电源端口最大6A，不带15个；调试时HAT与该DATA线断开。
3. 烧录/主控台架：电脑USB→读卡器→microSD写系统，拔卡再插Pi。Pi单独台架使用套装Micro-USB5V电源，此时断开HAT电池输入，避免双电源未经设计并联。可选显示器通过Mini-HDMI转接/HDMI线；可选USB外设通过Micro-USB OTG。电脑可经Wi-Fi/SSH连接Pi。
4. 散热片为贴装/固定，不接电线。万用表、烙铁、卡尺、压接工具是机外工具，不永久接入机器人。轴承、螺钉、铜柱不是电连接对象，图不画机械装配或3D打印件。

## 图的验收边界

核查对象是图中硬件是否齐全、连接端点/标签是否与上述已确认资料一致、互斥工况是否混接。BNO/ToF具体载板电压与接口细节、保护配电额定、软件总线配置及带载能力仍未知，图中使用待核标记，不宣称已经通过实机电气测试。

## 资料

- HAT固定版本：https://github.com/pollen-robotics/elec_RPI_Robot_HAT/tree/23eab11927f95ceca0dfa35bf182caeb7db39ea0 。本地直接读原理图main/dynamixel/audio/sensors及生产BOM，核对J4/J13/J14/J1。TH1位于TTL信号链，不把它误称为15舵机动力保护。
- HD-1910-C001串型规格书-20260907.pdf：用户附件，第3～4页（4～8.4V、7.4V额定0.9A/堵转2A、AMP2.0-3P，1DATA2VCC3GND）。
- URT-1使用说明(1).pdf：用户附件，第1～3页（Mini-USB、5264-3AW、5.08端子、最大6A）。
- 充电器同型号说明书：https://m.media-amazon.com/images/I/B1HhPqCEHML.pdf 。实际版本仍按随箱说明确认。
- Grove NFC：https://wiki.seeedstudio.com/Grove_NFC/ 。3.3V、分体天线、UART默认及改I2C焊点。
- TCA9548A：https://www.ti.com/product/TCA9548A 。
- VL53L8CX：https://www.st.com/resource/en/datasheet/vl53l8cx.pdf 。裸芯片电气条件不等于第三方载板接口电平。
- BNO085参考：https://learn.adafruit.com/adafruit-9-dof-orientation-imu-fusion-breakout-bno085/python-circuitpython 。只用于Pi/I2C兼容性参考，不替代用户紫色载板原理图。

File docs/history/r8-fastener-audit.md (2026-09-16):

> 历史参考：对应旧版硬件/几何；不得视为 R9 当前 BOM、接线或打印放行。

# R8 螺丝、轴承与备料总表

## 2026-09-13：轴承与一次备料总表

本次重新读取正在打开的 Blender 场景，38 个打印件、15 个舵机和14个轴承，共67个对象的网格/变换与已审磁盘文件一致。轴承逐个测量内径、外径和宽度，不是只看文件名。原模型与未保存状态保留。

### A. 轴承：型号、尺寸和模型数量已直接核实

尺寸顺序统一为 **内径 × 外径 × 厚度**，单位 mm。选无凸缘、普通内圈宽度的径向深沟球轴承。

| 型号/订货描述 | 尺寸 mm | 模型实需 | 建议购买 |
|---|---|---:|---:|
| MR2216-ZZ，金属防尘盖 | 16×22×4 | 11 | 12 |
| 6700 开式，或明确标注 W3 的 3 mm 厚版本 | 10×15×3 | 3 | 4 |

大轴承分布：躯干两处、左右腿各三处、头颈三处，共11个。小轴承分布：左右脚踝各1个，头/喙侧1个，共3个。

MR2216-ZZ 的尺寸对应 [MBA 目录第117页](https://files.minibearings.au/pdf/catalogues/Bearings%20-%20Radial%20-%20Master%20List.pdf#page=117)。[Runstar 6700开式](https://www.runstarbearing.com/product/thin-section-ball-bearings-6700/) 为10×15×3；[ISK 6700ZZ](https://iskbearing.com/product-details/6700zz) 为10×15×4。订货以三个尺寸为准，标4 mm厚的6700ZZ/2RS不作为当前3 mm位置的直接替换。

### B. 螺丝：一次备料建议，与轴承的直接确认数量分开

**以下是备料数，不是全机实装净用量。** 为形成可执行的长度组合，对108个舵机候选固定位置临时采用“接收端兼容M2、啮合1.5–3.0 mm、尽量接近2.0 mm”的计算场景，再加入22个非舵机名义选型位置。模型未标注的HD-1910牙型和允许深度仍未被确认；若为塑料专用自攻牙，应使用匹配牙型的配套螺丝，而不是把机牙螺丝强行代用。

| 规格 | 场景计算分配，非实需 | 建议购买备料数 |
|---|---:|---:|
| M2×3 | 18 | 30 |
| M2×4 | 32 | 40 |
| M2×5 | 54 | 60 |
| M2×6 | 15 | 30 |
| M2×8 | 备用，未指定安装位 | 10 |
| M2.5×5 | 4 | 10 |
| M2.5×8 | 7 | 15 |

上述机牙备料选择平底承压的内六角圆柱头，常规304不锈钢即可；不要统一购买锥形沉头。对板卡螺丝还应核对实际螺帽外径与周围元件空间。M2×8列为备用，不声称模型必用10颗。

轴心原配螺丝和相机/镜头固定不被擅自计入场景130个安装位；源模型保留的偏孔与螺柱复查项仍见下文，采购备料不等于这些问题已经修复。

### C. 小配件

| 配件 | 模型明确使用量 | 建议购买 |
|---|---:|---:|
| M2薄平垫，参考内径2.2、外径4.0、厚0.3 mm | OpenRB 4片 | 10片 |
| M2.5薄平垫，参考内径2.7、外径4.5、厚0.3 mm | Pi 4片 | 10片 |
| M2普通螺母 | 通孔试配备用，不按必装件计算 | 10个 |
| M2.5普通螺母 | 通孔试配备用，不按必装件计算 | 10个 |

模型没有把所有1.6 mm导孔设计为热熔螺母孔；本表不建议直接往这些小孔压入热熔螺母。

### D. 逐个轴承对应

| 模型对象 | 型号对应 | 内径×外径×厚度 mm |
|---|---|---|
| `PART_01_trunk_base_seeed_bearing__configuration__22x16x4` | MR2216-ZZ | 16×22×4 |
| `PART_08_trunk_base_seeed_bearing__configuration__22x16x4` | MR2216-ZZ | 16×22×4 |
| `PART_10_yaw2roll_seeed_bearing__configuration__22x16x4` | MR2216-ZZ | 16×22×4 |
| `PART_12_hip_l_seeed_bearing__configuration__22x16x4` | MR2216-ZZ | 16×22×4 |
| `PART_16_upper_leg_left_seeed_bearing__configuration__22x16x4` | MR2216-ZZ | 16×22×4 |
| `PART_20_ankle_left_seeed_bearing__configuration_default` | 6700 OPEN / W3 (3 mm width) | 10×15×3 |
| `PART_25_neck_pitch_seeed_bearing__configuration__22x16x4` | MR2216-ZZ | 16×22×4 |
| `PART_27_yaw_roll_motion_seeed_bearing__configuration__22x16x4` | MR2216-ZZ | 16×22×4 |
| `PART_28_yaw_roll_motion_seeed_bearing__configuration__22x16x4` | MR2216-ZZ | 16×22×4 |
| `PART_34_jaw_soft_seeed_bearing__configuration_default` | 6700 OPEN / W3 (3 mm width) | 10×15×3 |
| `PART_45_bearing_roll_seeed_bearing__configuration__22x16x4` | MR2216-ZZ | 16×22×4 |
| `PART_47_hip_l_2_seeed_bearing__configuration__22x16x4` | MR2216-ZZ | 16×22×4 |
| `PART_48_upper_leg_right_seeed_bearing__configuration__22x16x4` | MR2216-ZZ | 16×22×4 |
| `PART_54_ankle_right_seeed_bearing__configuration_default` | 6700 OPEN / W3 (3 mm width) | 10×15×3 |

本次测量及备料假设数据（历史本地资料）

---

## 结论

已重新读取当前 Blender 场景和磁盘 R8 浅紫黑装配文件；38 个装配打印件和 15 个 HD-1910 的网格、变换一致。当前场景的未保存状态保持不变，模型文件未保存、未修改。相机代理在当前场景与磁盘版本中不同，本次未覆盖当前场景。

**这份报告区分“孔位数量”“名义螺丝选型”和“实物适配”。当前模型没有完整的螺丝实体与螺纹数据，整机最终采购表仍有待定项。上一轮建议的短螺丝套装不是经确认的全机 BOM。**

## 1. 非舵机侧：22 个安装位的名义选型

下列新选型以接收孔形成对应公制螺纹为条件；打印导孔本身不等于现成机牙螺纹。型号中的长度按头下长度计。板卡规格沿用 R8 明文设计，其他规格由同轴孔、肩面、夹持厚度及底孔深度选取。未做实物螺纹拉脱、预紧、工具可达性或动态验证。

| 名义规格 | 安装位数量 | 分配 | 当前复核状态 |
|---|---:|---|---|
| M2×4 | 4 | OpenRB 四孔；配 0.3 mm 薄垫片 | 长度有余量；1 个接收柱的环向材料采样需要复查 |
| M2×6 | 7 | BNO 压片 2、开关压片 2、左右脚/踝连接各 1、左右躯干壳接合 1 | 长度有余量；1 个 BNO 接收柱需复查；躯干接合孔存在约 0.079 mm 轴线偏差 |
| M2.5×5 | 4 | Pi Zero 2 W 四孔；配 0.3 mm 薄垫片 | 长度有余量；2 个接收柱的环向材料采样需要复查 |
| M2.5×8 | 7 | 上下头壳 3、内部支架与下头壳 4 | 新增的条件选型；同轴孔及名义长度已复核 |
| 合计 | 22 | 不含舵机侧、轴心紧固、相机/镜头组件 | 不是整机螺丝总数 |

头型应保持平底承压。结构圆柱沉孔与锥形沉头孔不是一回事；目前长度表未等同于所有螺帽和工具均通过完整空间验证。

## 2. 舵机侧安装位已重新计数，牙型/长度待厂家资料

- 舵盘孔圈匹配到 **68 个独立安装位**。旧表的 54 个只是一个不完整子集。
- 机壳孔型匹配得到 42 个穿孔特征，底座/电源托架有 2 对共用轴线；去重后得到 **40 个候选紧固轴线**，其中 **39 处名义对齐，1 处偏置 0.50 mm**。
- 右躯干壳 `PART_02_trunk_base_right_shell` 的 `B027` 对应第 2 个舵机机壳候选孔，径向偏差 0.50 mm，超过 Ø2.2 过孔对 M2 螺杆的名义单边 0.10 mm 余量。该位置需要处理配合，再锁定装配。
- 四个轴心紧固候选位位于 `PART_09`、`PART_43`、`PART_17`、`PART_51`；中心螺丝是否使用舵机原配、是否需要换长，按厂家轴心螺纹和有效深度确认，不直接按 15×2 重复购买。
- 机壳接合位的夹持厚度约 0.8–3.2 mm，舵盘接合位约 1.8–4.3 mm。统一采用 M2×4 或 M2×6 会改变实际拧入深度，当前缺少厂家允许深度，故没有将其填成已确认型号。

厂家需补充：舵盘孔圈和机壳孔分别采用机牙还是塑料自攻/成形牙、名义直径与螺距、最大/推荐拧入深度、中心螺丝规格、随件数量。孔径 Ø1.6 不能替代以上螺纹标注。

### 舵盘孔圈安装位分布

| 打印件 | 安装位 |
|---|---:|
| `PART_02_trunk_base_right_shell` | 4 |
| `PART_07_trunk_base_left_shell` | 4 |
| `PART_09_yaw2roll_yaw2roll` | 4 |
| `PART_13_hip_l_hip_l` | 8 |
| `PART_17_leg_leg` | 4 |
| `PART_21_ankle_left_ankle_left` | 4 |
| `PART_24_neck_pitch_neck_pitch` | 12 |
| `PART_26_yaw_roll_motion_yaw_roll_motion` | 4 |
| `PART_38_jaw_soft_jaw` | 4 |
| `PART_43_bearing_roll_yaw2roll` | 4 |
| `PART_46_hip_l_2_hip_l` | 8 |
| `PART_51_leg_2_leg` | 4 |
| `PART_52_ankle_right_ankle_right` | 4 |

### 机壳候选轴线分布（共用穿孔已去重）

| 穿过的打印件 | 轴线数量 |
|---|---:|
| `PART_02_trunk_base_right_shell` | 1 |
| `PART_04_trunk_base_trunk_base` | 2 |
| `PART_04_trunk_base_trunk_base + PART_05_trunk_base_power_support` | 2 |
| `PART_05_trunk_base_power_support` | 2 |
| `PART_07_trunk_base_left_shell` | 1 |
| `PART_09_yaw2roll_yaw2roll` | 2 |
| `PART_11_yaw2roll_bearing_roll` | 2 |
| `PART_15_upper_leg_left_upper_leg_rigidity_plate` | 4 |
| `PART_17_leg_leg` | 2 |
| `PART_22_neck_neck` | 4 |
| `PART_23_neck_neck` | 4 |
| `PART_26_yaw_roll_motion_yaw_roll_motion` | 4 |
| `PART_43_bearing_roll_yaw2roll` | 2 |
| `PART_44_bearing_roll_bearing_roll` | 2 |
| `PART_49_upper_leg_right_upper_leg_rigidity_plate` | 4 |
| `PART_51_leg_2_leg` | 2 |

## 3. 保留问题与排除项

- 不计入旧 Robot HAT、旧 ToF 两个压片、5 个独立试装片的螺丝。
- 相机/镜头固定、旧 PCB 锁条和若干未配对预留孔未被擅自视为已确定装机螺丝。孔特征不按“一孔一颗”累计。
- R8 内支架按螺纹小径与大径之间的环向材料采样，P02、P04、P05，以及 BNO 位 P09 出现部分空缺样本。这是复查提示，不是拉脱强度试验结果。
- 上下头壳在原始闭合坐标下有约 67.89 mm³ 实体交集；本轮只记录，没有移动或修改头壳。数字孔位匹配不等同于整套打印件已实装通过。

## 4. 逐个非舵机侧连接的测量记录

| ID | 用途 | 规格 | 夹持厚度 mm | 名义啮合 mm | 到孔底余量 mm | 环向材料采样占比 | 状态 |
|---|---|---|---:|---:|---:|---:|---|
| P01 | Pi Zero 2 W | M2.5x5 | 1.900 | 3.100 | 1.200 | 1.000 | NOMINAL_LENGTH_FITS |
| P02 | Pi Zero 2 W | M2.5x5 | 1.900 | 3.100 | 1.200 | 0.958 | REVIEW_REQUIRED |
| P03 | Pi Zero 2 W | M2.5x5 | 1.900 | 3.100 | 1.200 | 1.000 | NOMINAL_LENGTH_FITS |
| P04 | Pi Zero 2 W | M2.5x5 | 1.900 | 3.100 | 1.200 | 0.875 | REVIEW_REQUIRED |
| P05 | OpenRB-150 | M2x4 | 1.900 | 2.100 | 1.400 | 0.542 | REVIEW_REQUIRED |
| P06 | OpenRB-150 | M2x4 | 1.900 | 2.100 | 1.400 | 1.000 | NOMINAL_LENGTH_FITS |
| P07 | OpenRB-150 | M2x4 | 1.900 | 2.100 | 1.400 | 1.000 | NOMINAL_LENGTH_FITS |
| P08 | OpenRB-150 | M2x4 | 1.900 | 2.100 | 1.400 | 1.000 | NOMINAL_LENGTH_FITS |
| P09 | BNO edge clamp | M2x6 | 0.700 | 5.300 | 0.650 | 0.833 | REVIEW_REQUIRED |
| P10 | BNO edge clamp | M2x6 | 1.550 | 4.450 | 0.650 | 1.000 | NOMINAL_LENGTH_FITS |
| P11 | Slide-switch retainer | M2x6 | 1.650 | 4.350 | 3.400 | 1.000 | NOMINAL_LENGTH_FITS |
| P12 | Slide-switch retainer | M2x6 | 1.650 | 4.350 | 3.400 | 1.000 | NOMINAL_LENGTH_FITS |
| P13 | Foot to ankle | M2x6 | 2.000 | 4.000 | 1.500 | 1.000 | NOMINAL_LENGTH_FITS |
| P14 | Foot to ankle | M2x6 | 2.000 | 4.000 | 1.500 | 1.000 | NOMINAL_LENGTH_FITS |
| P15 | Left/right trunk shell join | M2x6 | 2.800 | 3.200 | 1.500 | 1.000 | NOMINAL_LENGTH_FITS |
| P16 | Upper/lower head shell | M2.5x8 | 2.804 | 5.196 | 6.004 | 1.000 | NOMINAL_LENGTH_FITS |
| P17 | Upper/lower head shell | M2.5x8 | 2.804 | 5.196 | 6.004 | 1.000 | NOMINAL_LENGTH_FITS |
| P18 | Upper/lower head shell | M2.5x8 | 2.804 | 5.196 | 6.004 | 1.000 | NOMINAL_LENGTH_FITS |
| P19 | Internal carrier to lower head shell | M2.5x8 | 2.400 | 5.600 | 3.700 | 1.000 | NOMINAL_LENGTH_FITS |
| P20 | Internal carrier to lower head shell | M2.5x8 | 2.400 | 5.600 | 3.700 | 1.000 | NOMINAL_LENGTH_FITS |
| P21 | Internal carrier to lower head shell | M2.5x8 | 2.400 | 5.600 | 3.700 | 1.000 | NOMINAL_LENGTH_FITS |
| P22 | Internal carrier to lower head shell | M2.5x8 | 2.400 | 5.600 | 3.616 | 1.000 | NOMINAL_LENGTH_FITS |

## 5. 复核方法与文件

1. 对当前场景做只读网格导出，另外使用 Blender 后台打开磁盘文件导出对照；没有覆盖用户的未保存内容。
2. 从三角网格提取内凹圆柱面；同轴台阶/沉孔合并为一个孔特征，避免把孔口两面算成两颗螺丝。
3. 将孔轴与已保留的舵机运动学坐标、12 mm 舵盘孔圈和 30×16 mm 机壳名义孔型比较。
4. 对打印件之间的接收孔、夹持厚度、底孔余量进行复算，明确列出推断与待确认项。
5. 用带沉孔的合成样件回归测试确认“两段圆柱面对应一个紧固轴线”。

源模型：[LOCAL_PATH]

SHA-256：`65b51e8ec352e212dee833e8251a91c4132a9aabef6cf057ad519c725064edf5`

- 孔特征（历史本地资料）
- 接口去重与偏置记录（历史本地资料）
- 逐位名义选型（历史本地资料）
- 验证结果（历史本地资料）
- 可复现命令及字面输出（历史本地资料）

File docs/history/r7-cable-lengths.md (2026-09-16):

> 历史参考：对应旧版硬件/几何；不得视为 R9 当前 BOM、接线或打印放行。

# 线长与运动余量参考

这些数值来自当前模型路径和159组源关节姿态的端点跨度。它们不是裁线长度，也不证明软线弯折、夹线或疲劳通过。

| 编号 | 模型路径 mm | 最大端点跨度 mm | 试装备线参考 mm | 注意 |
|---|---:|---:|---:|---|
| C01a | 5.0 | 9.1 | 40 | 端头、线径与动态余量待核；当前路径仍需增加余量 |
| C01b | 8.0 | 6.1 | 40 | 端头、线径与动态余量待核；当前路径仍需增加余量 |
| C02 | 162.9 | 155.8 | 200 | 端头、线径与动态余量待核；当前路径仍需增加余量 |
| C03 | 179.2 | 157.5 | 220 | 端头、线径与动态余量待核 |
| C04_LEFT | 57.2 | 34.1 | 90 | 端头、线径与动态余量待核 |
| C04_RIGHT | 89.2 | 40.6 | 120 | 端头、线径与动态余量待核 |
| C04_NECK | 54.4 | 49.2 | 80 | 端头、线径与动态余量待核；当前路径仍需增加余量 |
| C04_LEFT_DISTAL | 149.3 | 138.0 | 180 | 端头、线径与动态余量待核 |
| C04_RIGHT_DISTAL | 150.0 | 139.0 | 190 | 端头、线径与动态余量待核 |
| C04_HEAD | 105.7 | 126.2 | 160 | 端头、线径与动态余量待核；当前路径仍需增加余量 |
| C05_L1 | 59.9 | 36.3 | 150 | 原配150mm先复用，余线布置需核对 |
| C05_L2 | 41.9 | 37.5 | 150 | 原配150mm先复用，余线布置需核对；当前路径仍需增加余量 |
| C05_L3 | 33.6 | 34.5 | 150 | 原配150mm先复用，余线布置需核对；当前路径仍需增加余量 |
| C05_L4 | 64.1 | 54.7 | 150 | 原配150mm先复用，余线布置需核对；当前路径仍需增加余量 |
| C05_R1 | 49.0 | 35.2 | 150 | 原配150mm先复用，余线布置需核对 |
| C05_R2 | 46.1 | 37.5 | 150 | 原配150mm先复用，余线布置需核对；当前路径仍需增加余量 |
| C05_R3 | 20.6 | 21.1 | 150 | 原配150mm先复用，余线布置需核对；当前路径仍需增加余量 |
| C05_R4 | 61.7 | 54.7 | 150 | 原配150mm先复用，余线布置需核对；当前路径仍需增加余量 |
| C05_H1 | 34.8 | 35.3 | 150 | 原配150mm先复用，余线布置需核对；当前路径仍需增加余量 |
| C05_H2 | 53.5 | 38.8 | 150 | 原配150mm先复用，余线布置需核对 |
| C05_H3 | 83.5 | 65.1 | 150 | 原配150mm先复用，余线布置需核对 |
| C05_H4 | 76.9 | 57.3 | 150 | 原配150mm先复用，余线布置需核对 |
| C06 | 54.0 | 45.2 | 80 | 端头、线径与动态余量待核；当前路径仍需增加余量 |
| C07 | 84.2 | 68.3 | 110 | 端头、线径与动态余量待核 |
| C08 | 131.0 | 126.0 | 160 | 端头、线径与动态余量待核；当前路径仍需增加余量 |
| C09 | 51.1 | 42.4 | 80 | 端头、线径与动态余量待核；当前路径仍需增加余量 |
| C10 | 71.5 | 54.1 | 100 | 端头、线径与动态余量待核 |
| C11_HEAD | 110.0 | 86.7 | 140 | 端头、线径与动态余量待核 |
| C11_MOUTH | 88.9 | 77.7 | 120 | 端头、线径与动态余量待核 |
| C12_HEAD | 62.8 | 58.0 | 90 | 原配同轴不按本表裁短/加长；当前路径仍需增加余量 |
| C12_MOUTH | 15.7 | 9.6 | 50 | 原配同轴不按本表裁短/加长；当前路径仍需增加余量 |

检查只计算端点距离下界，不包含真实软线弯曲、夹具约束、扭转、磨损或通电状态。原配线头和未量出的端接段会进一步影响实际线长。
机内只建C01–C12对应路径；C13–C20为机外调试/充电附件。

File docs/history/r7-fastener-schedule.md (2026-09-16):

> 历史参考：对应旧版硬件/几何；不得视为 R9 当前 BOM、接线或打印放行。

# 紧固件方案用量（不是直接补购单）

本轮新增60个螺钉模型；总计80个新增紧固件/隔离件参考实体。先核对舵机和板卡随件，再确定补购数量。

| 类型 | 参考规格 | 模型用量 | 用途/处理 |
|---|---|---:|---|
| 螺母 | M2 | 2 | Pi/HAT叠层或BNO夹持试装；实际规格/配合待核 |
| 螺母 | M2.5 | 4 | Pi/HAT叠层或BNO夹持试装；实际规格/配合待核 |
| 螺钉 | M2.5x14 | 4 | Pi/HAT叠层或BNO夹持试装；实际规格/配合待核 |
| 螺钉 | M2x4 | 8 | 源结构圆孔与舵盘12mm孔圈匹配；长度按名义叠厚选择 |
| 螺钉 | M2x5 | 38 | 源结构圆孔与舵盘12mm孔圈匹配；长度按名义叠厚选择 |
| 螺钉 | M2x6 | 8 | 源结构圆孔与舵盘12mm孔圈匹配；长度按名义叠厚选择 |
| 螺钉 | M2x8 | 2 | Pi/HAT叠层或BNO夹持试装；实际规格/配合待核 |
| 隔离柱/套管 | ID2.8 OD5 L6.4 | 4 | Pi/HAT叠层或BNO夹持试装；实际规格/配合待核 |
| 垫片 | ID2.2 OD5.0 t0.3 | 2 | Pi/HAT叠层或BNO夹持试装；实际规格/配合待核 |
| 垫片 | ID2.2 OD5.0 t0.5 | 4 | Pi/HAT叠层或BNO夹持试装；实际规格/配合待核 |
| 垫片 | ID2.7 OD4.5 t0.5 | 4 | Pi/HAT叠层或BNO夹持试装；实际规格/配合待核 |

## 已有与未计入补购的项目
- 原ToF的M2×5螺钉、M2螺母、0.3mm垫片各2件仍保留，未重复算入本轮新增80件。
- 舵机参考CAD内部已有中心/壳体紧固件；30个两侧中心标识只是部件内参考，不等于再买30颗。
- 新规格图标总厚29mm，现有参考CAD的轴侧包络约30.2mm；先做单组接口试装，再放行螺钉长短与啮合深度。
- 源模型中约Ø1.6的孔没有被直接套成M2机牙孔。未分类孔位标记是圆周边界候选，不等于螺丝数量。
- M2.5小外径垫片、6.4mm隔离高度及螺钉头型需要按实际排针、板厚和附近接插件确认。
- Pi/HAT托架和BNO夹座是试装原型，固定到现有主结构的方法尚未全部放行。

## 定位方法
Blender中F_HORN_开头为舵盘接口候选；F_HAT_为主控叠层；F_BNO_为IMU夹座。对象自定义属性含规格、宿主零件、来源孔位和状态。

详细实例记录：FASTENERS_BUILT.json。未经逐处实物确认，不把该表视作最终采购数量。

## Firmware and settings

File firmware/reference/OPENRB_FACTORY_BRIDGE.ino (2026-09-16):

// Copyright 2022 ROBOTIS CO., LTD.
//
// Licensed under the Apache License, Version 2.0 (the "License");
// you may not use this file except in compliance with the License.
// You may obtain a copy of the License at
//
//     http://www.apache.org/licenses/LICENSE-2.0
//
// Unless required by applicable law or agreed to in writing, software
// distributed under the License is distributed on an "AS IS" BASIS,
// WITHOUT WARRANTIES OR CONDITIONS OF ANY KIND, either express or implied.
// See the License for the specific language governing permissions and
// limitations under the License.

#include <Dynamixel2Arduino.h>

#define DXL_BUS Serial1
#define USB Serial
#define DXL_PACKET_BUFFER_LENGTH  1024

uint8_t packet_buffer[DXL_PACKET_BUFFER_LENGTH];
unsigned long led_update_time = 0;

Dynamixel2Arduino dxl(DXL_BUS);

void setup() {
  // put your setup code here, to run once:
  pinMode(LED_BUILTIN, OUTPUT);
  // Use UART port of DYNAMIXEL Shield to debug.
  USB.begin(57600);
  
  // Set Port baudrate to 57600bps. This has to match with DYNAMIXEL baudrate.
  dxl.begin(USB.baud());
  // Set Port Protocol Version. This has to match with DYNAMIXEL protocol version.
}

void loop() {
  // put your main code here, to run repeatedly:
  dataTransceiver();

  if(USB.baud() != dxl.getPortBaud()) {
    dxl.begin(USB.baud());
  }
}

void dataTransceiver()
{
  int length = 0;
  int i = 0;

  // USB -> DXL
  length = USB.available();
  if( length > 0 )
  {
    for(i = 0; i < length; i++)
    {
      DXL_BUS.write(USB.read());
    }
    ledStatus();
  }

  // DXL -> USB
  length = DXL_BUS.available();
  if( length > 0 )
  {
    if( length > DXL_PACKET_BUFFER_LENGTH )
    {
      length = DXL_PACKET_BUFFER_LENGTH;
    }
    for(i = 0; i < length; i++)
    {
      packet_buffer[i] = DXL_BUS.read();
    }
    USB.write(packet_buffer, length);
    ledStatus();
  }
}

void ledStatus()
{
  if((millis() - led_update_time) > 200 )
  {
    digitalWrite(LED_BUILTIN, 1);
    led_update_time = millis();
  } else {
    digitalWrite(LED_BUILTIN, 0);
  }
}
